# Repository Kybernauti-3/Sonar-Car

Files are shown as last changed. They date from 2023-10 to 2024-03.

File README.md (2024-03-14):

# Sonar-Car
Auticko ktere jezdi po mistnoti a vytváří její mapu

# Použité součástky

2x Rpi pi pico

https://botland.cz/img/art/inne/21574_3.jpg

[Motory kol](https://www.laskakit.cz/dc-motorek-130-3v-16500-rpm/)

[Otočná kontaktní průchodka, 4 vodiče](https://www.laskakit.cz/otocna-kontaktni-pruchodka--4-vodice/)

[Ultrazvukový senzor vzálenosti](https://www.laskakit.cz/ultrazvukovy-meric-vzdalenosti-hc-sr04/)

https://www.laskakit.cz/h-mustek-radic-l9110s/

https://www.laskakit.cz/krokovy-motor-28byj-48/

Mecanum Omni Wheels

Drátování

# Software tohoto projektu je rozdělen na 3 části:

## 1. Program pro řízení vozítka:
Tento program bude řídit pohyb vozítka v souřadnicovém poli. Bude přijímat příkazy k pohybu a posunutí o určitý počet souřadnic (např. 10 cm) v daném směru. Zahrnuje:

- Řízení motorů omniwheelů pro pohyb ve všech směrech.
- Komunikaci přes sériovou linku s druhou deskou.
- API pro přijímání povelů k pohybu o určitý počet souřadnic v daném směru (dopředu, dozadu, doleva, doprava).
- Překlad příkazů na konkrétní pohyby omni kol pro dosažení požadovaného cíle v souřadnicovém poli.

## 2. Program pro mapování místnosti:
Tento program bude kromě mapování také přijímat aktuální polohu vozítka od skriptu pro řízení vozidla. Zahrnuje:

- Vytváření mapy místnosti, kde jedna jednotka bude reprezentovat 10 cm v reálném světě.
- Aktualizaci mapy na základě nových dat z ultrazvukového senzoru.
- Ukládání dat do pole, které reprezentuje mapu místnosti.
- Poskytování těchto informací skriptu pro řízení vozidla.

## 3. Skript pro řízení vozidla na základě mapy:
Tento skript bude řídit pohyb vozidla na základě aktuální mapy místnosti a bude poskytovat aktuální informace o svém pohybu programu pro mapování. Zahrnuje:

- Analýzu dat z mapy a aktuální polohy k rozhodování, kam se vozidlo má pohybovat.
- Generování možných směrů pro pohyb vozidla.
- Vybrat z těchto směrů takový, aby se vozidlo pohnulo pryč a zároveň zabezpečit, aby se v dalším kroku nevrátilo zpět
- Odesílání vybraného směru programu pro řízení vozidla.
- Tímto způsobem bude projekt umožňovat vozítku pohybovat se v místnosti, mapovat prostor a řídit svůj pohyb na základě aktuální mapy.

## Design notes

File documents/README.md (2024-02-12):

# Sonar-Car
Zde se nachází veškeré dokumenty, soupisky a prezentace

# LaTeX

https://www.overleaf.com/read/rbjfbvbgkymk#7530cc

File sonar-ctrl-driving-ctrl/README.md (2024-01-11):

# Sonar-Car
Zde se nachází skripty pro řízení "sonaru" a skript který rozhoduje kam vozidlo pojede

- Měřič na vzdálenost musí být zapojenej ve VBUSu 
- motor taky

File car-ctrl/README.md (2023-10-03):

# Sonar-Car
Zde se nachází skripty pro ovládaní kol auta a jeho pohyb

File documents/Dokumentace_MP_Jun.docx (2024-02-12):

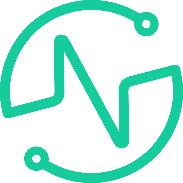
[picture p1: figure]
Obsah obrázku Grafika, Písmo, kruh, symbol Popis byl vytvořen automaticky

Vyšší odborná škola

a Střední průmyslová škola elektrotechnická

Plzeň, Koterovská 85

Dlouhodobá maturitní práce s obhajobou

Téma: Sonar Car

Autor práce: Matěj Jun

Třída: 4. L

Vedoucí práce: Jiří Švihla

Dne: 27. 3. 2024

Hodnocení:

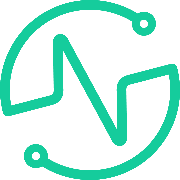
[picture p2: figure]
Obsah obrázku Grafika, Písmo, kruh, symbol Popis byl vytvořen automaticky

Vyšší odborná škola

a Střední průmyslová škola elektrotechnická

Plzeň, Koterovská 85

Zadání dlouhodobé maturitní práce

Žák: Matěj JUN

Třída: 4. L

Studijní obor: 78-42-M/01 Technické lyceum

Zaměření: Kybernetika

Školní rok: 2023 - 2024

Téma práce: Sonar Car

Pokyny k obsahu a rozsahu práce:

1. Seznámení s vývojovou platformou Raspberry Pi Pico
2. Seznámení s modelovacím softwarem
3. Seznámení s problematikou orientace v prostoru a mapováním
4. Tvorba podvozku a návrh řídící elektroniky
5. Návrh a testování mapovací jednotky
6. Tvorba mapovacího skriptu
7. Realizace komunikace mezi jednotkami

Plán konzultací:

19. 10. 2023 Návrh modelu a elektroniky

23. 11. 2023 Kompletace hardwaru

11. 1. 2024 Práce na softwarovém vybavení

8. 2. 2024 Testování mapování a tvorba dokumentace

Určení částí tématu zpracovávaných jednotlivými žáky:

1. Seznámení s vývojovou platformou Raspberry pi pico
2. Seznámení s problematikou orientace v prostoru a mapováním
3. Naprogramujte mapování místnosti
4. Návrh a testování mapovací jednotky
5. Tvorba mapovacího skriptu
6. Realizace komunikace mezi jednotkami

Požadavek na počet vyhotovení maturitní práce: 2 výtisky

Termín odevzdání: 27. března 2024

Čas obhajoby: 15 minut

Vedoucí práce: Jiří ŠVIHLA

Projednáno v katedře ODP a schváleno ředitelem školy.

V Plzni dne: 30. září 2023 Mgr. Vlastimil Volák ředitel školy

## Anotace

Cílem této maturitní práce je vytvoření autonomního vozítka schopného pohybu a mapování místnosti. Práce využívá platformu Raspberry Pi Pico a orientaci vozítka zabezpečuje vzdálenostní senzor umístěný na střeše vozu. Pro pohyb jsou implementována všesměrová kola Mecanum Wheels, která umožňují vozítku pohybovat se ve všech směrech.

„Prohlašuji, že jsem tuto práci vypracoval samostatně a použil(a) literárních pramenů a informací, které cituji a uvádím v seznamu použité literatury a zdrojů informací.“

V Plzni dne: ........................... Podpis: ..............................

## Úvod

V dnešní době, kdy technologický pokrok zaujímá stále větší roli v našich životech, nabývá autonomní robotika a mapování prostoru stále většího významu. Tato maturitní práce si klade za cíl vytvořit malé autonomní vozítko, které se nejenom pohybuje po místnosti, ale také aktivně mapuje své okolí.

Využití platformy Raspberry Pi Pico poskytuje robustní základ pro implementaci řídícího systému vozítka. Hlavním prvkem orientace vozidla je ultrazvukový senzor, který je umístěný na střeše a umožní vozítku získávat informace o okolním prostoru. Pro zajištění plynulého pohybu byla zvolena technologie Omni-wheels, umožňující vozítku pohybovat se ve všech směrech s výjimečnou obratností.

Tato práce nikoli pouze zkoumá technické aspekty vývoje autonomního vozidla, ale také přispívá k pochopení principů autonomní robotiky a mapování prostoru. Výsledky projektu mohou sloužit nejen jako ukázka praktického využití technologií, ale také jako inspirace pro další výzkum v oblasti autonomních systémů.

## 1. Cíle a požadavky

### 1.1. Program pro mapování místnosti

Tento program kromě mapování také přijímá aktuální polohu vozítka od skriptu pro jeho řízení. Zahrnuje:

- Vytváření mapy místnosti, kde jedna jednotka bude reprezentovat 10 cm v reálném světě.
- Přijímání aktuální polohy vozítka od skriptu pro řízení vozidla.
- Aktualizaci mapy na základě nových dat z ultrazvukového senzoru.
- Ukládání dat do pole nebo souboru, který reprezentuje mapu místnosti.
- Poskytování těchto informací skriptu pro řízení vozidla na vyžádání.

### 1.2. Skript pro řízení vozidla na základě mapy

Skript bude řídit pohyb vozidla na základě aktuální mapy místnosti a poskytuje aktuální informace o svém pohybu části programu pro mapování. Zahrnuje:

- Pravidelně aktualizovat program pro mapování o svůj aktuální pohyb, včetně souřadnic.
- Analýzu dat z mapy a aktuální polohy k rozhodování, kam se vozidlo má pohybovat.
- Generování příkazů pro pohyb vozidla o určitý počet souřadnic (např. 10 cm) od překážky.
- Odesílání těchto příkazů programu pro řízení vozítka.
- Tímto způsobem bude projekt umožňovat vozítku pohybovat se v místnosti, mapovat prostor a řídit svůj pohyb na základě aktuální mapy.

## 2. Použité součástky

### 2.1. Raspberry Pi Pico W

Raspberry Pi Pico W je vývojová deska s mikrokontrolérem, která je založena na čipu RP2040 od společnosti Raspberry Pi Foundation. Čip obsahuje dvoujádrový procesor ARM Cortex-M0+ s taktem až 133 MHz, 264 kB paměti RAM a 2 MB vestavěné paměti Flash. Deska má 28 GPIO pinů, které lze použít pro připojení různých periferních zařízení, jako jsou senzory, LED diody, motory atd.

Vývojová deska Raspberry Pi Pico W je vhodná pro širokou škálu aplikací, včetně IoT, automatizace, domácí elektroniky a dalších. Je cenově dostupná a snadno se používá, což z ní činí ideální volbu pro začátečníky i pokročilé uživatele.

V tomto projektu je díky této desce ovládán krokový motor, zpracovávány data z ultrazvukového senzoru a řízeno celé vozítko. Verze s Wifi byla také zvolena pro možnost později mapu přenášet bezdrátově.

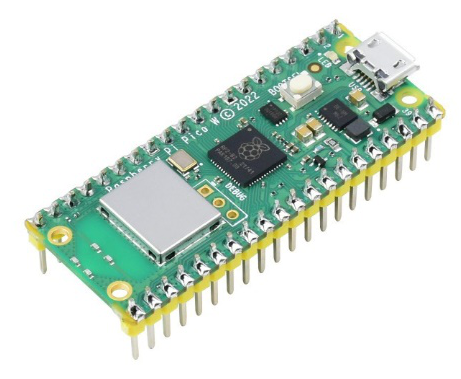
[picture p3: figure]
Raspberry Pi Pico W with Soldered Headers - RP2040 - WS-23289

Obrázek 1 - Raspberry Pi Pico W [Zdroj: https://www.tinytronics.nl/shop/image/cache/catalog/products_2023/raspberry-pi-pico-w-with-soldered-headers-rp2040-800x800.jpg]

### 2.2. Ultrazvukový senzor vzdálenosti

Ultrazvukový měřič vzdálenosti HC-SR04 je kompaktní a cenově dostupný senzor, který měří vzdálenost od překážky pomocí ultrazvukových vln. Senzor má pracovní rozsah od 2 cm do 4 m a přesnost měření až 3 mm.

Senzor pracuje na principu odrazu ultrazvukových vln od překážky. Senzor vysílá krátký impuls ultrazvukových vln a poté čeká na jejich odražení od překážky. Doba, za kterou se ultrazvukové vlny odrazí, se používá k výpočtu vzdálenosti od překážky.

V tomto projektu je použit pro měření vzdálenosti mezi „sonarem“ na vozítku a překážkami či zdmi.

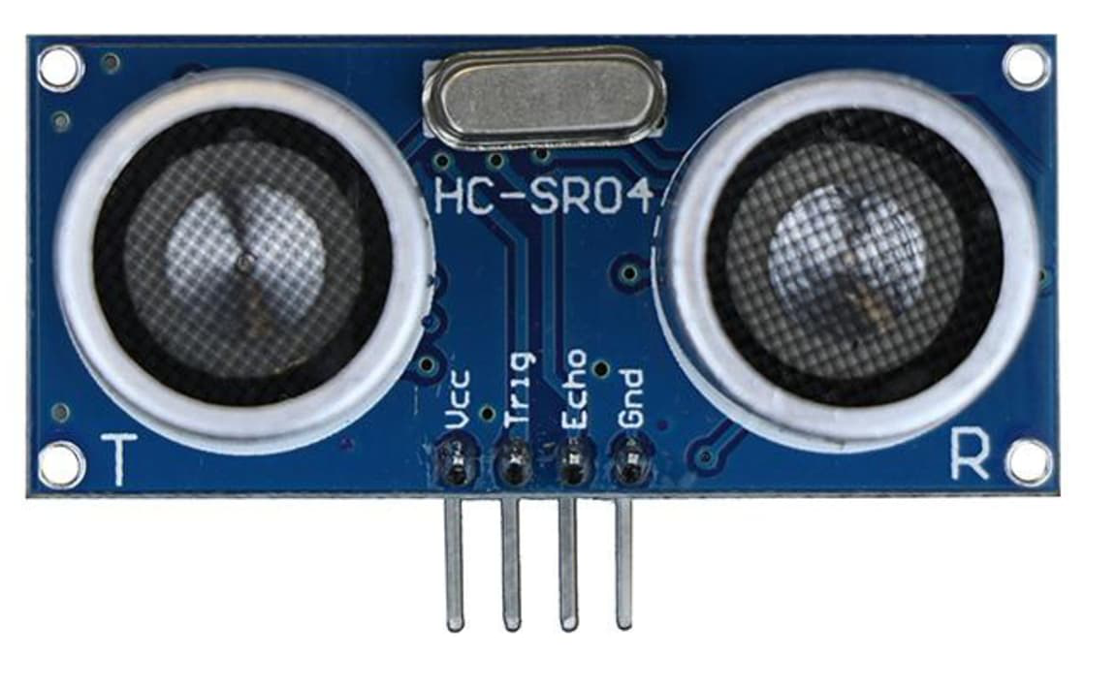
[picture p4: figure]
46130 | Ultrasonic Distance Sensor HC-SR04 5V Ve | RS

Obrázek 2 - Ultrazvukový měřič vzdálenosti HC-SR04 [Zdroj: https://cz.rs-online.com/web/p/doplnky-bbc-micro-bit/2153181] (https://cz.rs-online.com/web/p/doplnky-bbc-micro-bit/2153181)

### 2.3. Krokový motor

Krokový motor 28BYJ-48 je malý a cenově dostupný krokový motor, který se často používá v robotických aplikacích. Motor má 4 fáze a 48 zubů, což znamená, že pro jednu otáčku motoru je potřeba 48 kroků.

Motor pracuje na principu krokování, při kterém se motor otáčí po malém úhlu v každém kroku. Tímto způsobem lze motor ovládat přesně a plynule.

V tomto projektu je použit pro otáčení „sonaru“ s ultrazvukovým senzorem vzdálenosti.

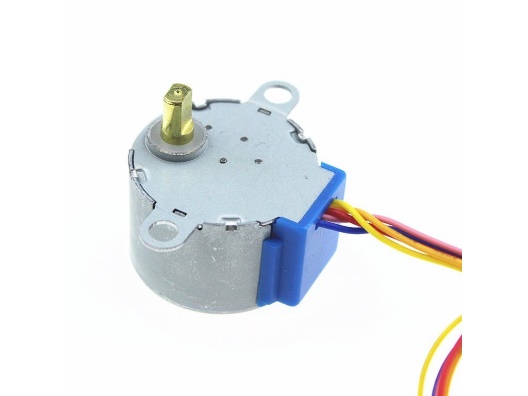
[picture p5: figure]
Obsah obrázku kabel, Elektrické vedení Popis byl vytvořen automaticky

Obrázek 3 - Krokový motor 28BYJ-48 [Zdroj: https://www.laskakit.cz/krokovy-motor-28byj-48/]

### 2.4. Řadič ULN2003

Díky řadiči ULN2003 lze s krokovým motorem jednoduše otáčet.

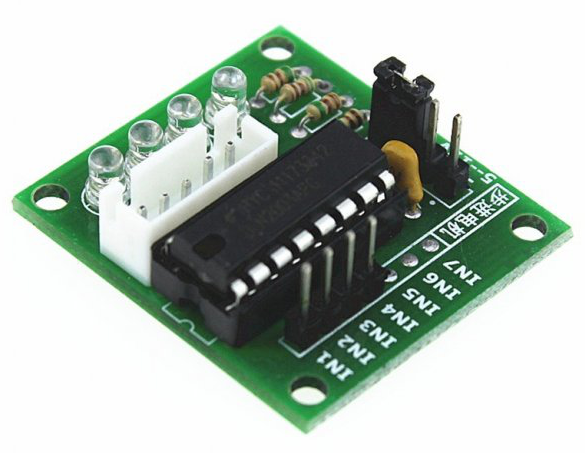
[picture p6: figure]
Obsah obrázku elektronika, Elektronická součástka, Obvodoví součástka, Pasivní součástka Popis byl vytvořen automaticky

Obrázek 4 - Řadič ULN2003 [Zdroj: https://www.laskakit.cz/radic-uln2003-pro-krokovy-motor/]

### 2.5. RGB LED

RGB LED je zkratka pro Light Emitting Diode (LED) s třemi základními barvami – červenou, zelenou a modrou. Jedná se o speciální typ LED diody, který umožňuje nezávislé ovládání těchto tří barev, což umožňuje vytváření široké škály barevných kombinací.

Zde je použita pro signalizování stavu sonaru.

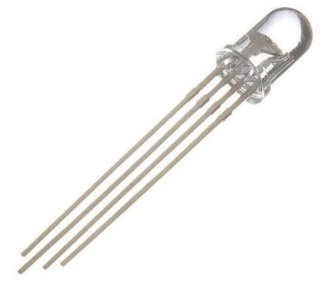
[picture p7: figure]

Obrázek 5 - RGB LED [Zdroj: https://dratek.cz/docs/produkty/1/1298/1434544602.pdf]

## 3. Ovládání sonaru

### 3.1. Měření vzdálenosti

„Sonar“ měří vzdálenost k objektu pomocí ultrazvukového senzoru (viz v kapitole použitých součástek). Senzor nejprve vysílá ultrazvukový impuls, který se odrazí od objektu a vrátí se zpět k senzoru. Čas, který impuls stráví cestou tam a zpět, se pak použije k výpočtu vzdálenosti k objektu pomocí vzorce:

vzdálenost= (čas*rychlost zvuku)/2

Jelikož impuls letí k překážce, kde se odrazí a stejnou rychlostí letí zpět je nutné vzdálenost vydělit dvěma. Funkce, která zajišťuje správný výpočet, vrací právě tuto přepočítanou vzdálenost, která je dále používána při zpracování mapy.

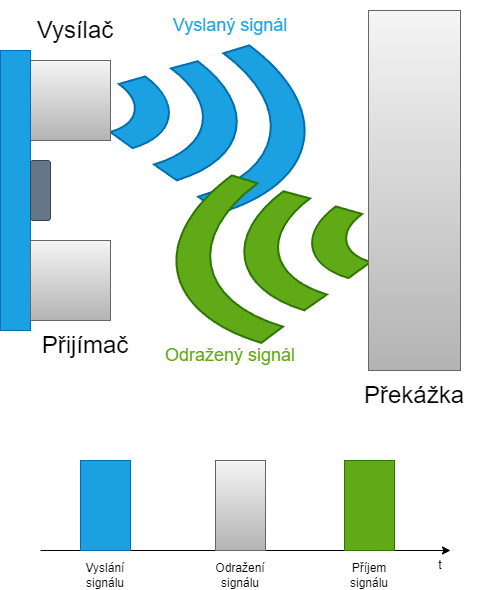
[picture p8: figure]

Obrázek 6 – Měření vzdálenosti [Zdroj: vlastní, vytvořeno pomocí draw.io]

### 3.2. Otáčení sonaru

Otáčení sonaru je zajištěno pomocí krokového motoru, který pohání mechanismus otáčení. Motor je ovládán příslušným řadičem, který přijímá signály z Raspberry Pi Pica a generuje odpovídající krokové impulzy. Tyto impulzy pohybují motorem a tím otáčejí sonar do požadovaného směru. Pro dosažení přesného a plynulého otáčení je nutné řádně řídit frekvenci a počet kroků motoru.

### 3.3. Taktika mapování

Taktika mapování místnosti je založena na pravidelném pohybu vozítka po místnosti s pevně definovanou taktikou. Vozítko je řízeno tak, aby se pohybovalo vždy o určitý krok, například 10 cm, od stěn místnosti, což odpovídá jedné souřadnici v mapě. Tímto způsobem je postupně zmapován celý prostor místnosti, zatímco senzor neustále snímá vzdálenost od překážek.

### 3.4. Vytváření mapy

Vytváření mapy místnosti je proces, při kterém jsou sbírána data z ultrazvukového senzoru a ukládána do pole reprezentujícího mapu. Každé snímání vzdálenosti od překážek je interpretováno jako bod v mapě, kde jednotlivé body jsou rozloženy v souřadnicovém systému. Na základě těchto bodů je poté vytvořena mapa místnosti, která poskytuje informace o umístění překážek a volných prostorů v místnosti. Tato mapa může být dále využita k navigaci vozítka v prostoru.

## 4. Model sonaru

### 4.1. Modelovací prostředí

Pro vymodelování sonaru byl zvolen program Autodesk Inventor Professional 2023. Je to profesionální program pro modelování komplexnějších modelů. Používá se hlavně v průmyslu k modelování například aut, bagrů či jiných průmyslových strojů.

V tomto projektu je použit pro vytvoření detailního modelu krabičky pro sonar.

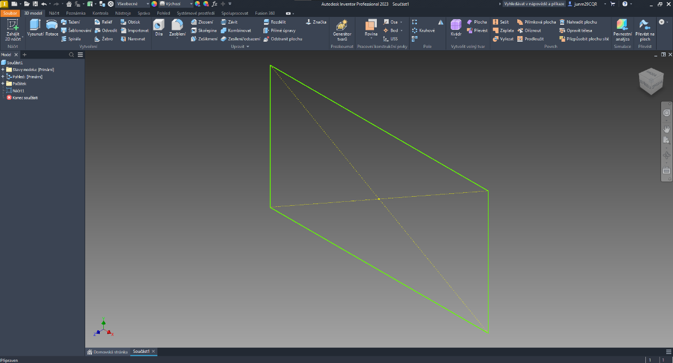
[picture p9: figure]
Obsah obrázku text, snímek obrazovky, software, Multimediální software Popis byl vytvořen automaticky

Obrázek 7 - Modelovací prostředí programu Autodesk Inventor [Zdroj: vlastní]

### 4.2. Postup modelování

Nejprve bylo důležité zvolit správné rozložení komponent v krabičce a zvolit jednoduchý, ale moderní a „vzdušný“ design.

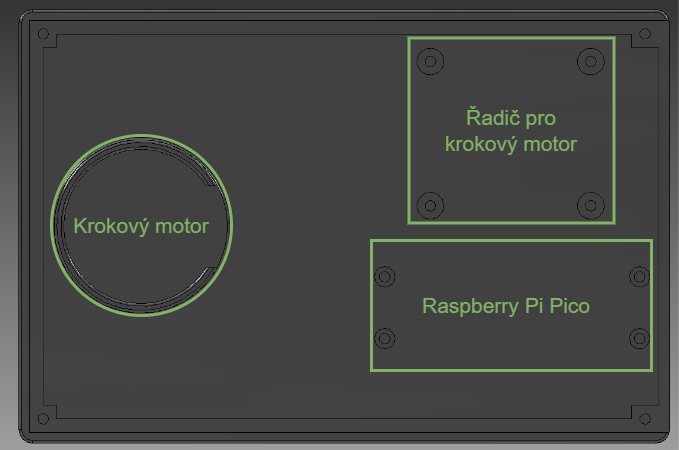
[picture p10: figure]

Obrázek 8 - Rozložení komponent v krabičce [Zdroj: vlastní, vytvořeno pomocí draw.io]

## 5. Závěr

Pokročilá verze tohoto sonaru, známá jako LiDAR (Light Detection And Ranging), otevírá široké možnosti využití. LiDAR lze použít nejen k mapování místností, ale také k měření vzdálenosti, mapování terénu, monitorování atmosférických jevů a mnoha dalším aplikacím. Výsledky tohoto projektu poskytují solidní základ pro další vývoj a vylepšení, což může vést k vytvoření pokročilejších a přesnějších systémů mapování. Tento projekt ukazuje, jak jednoduché vozítko s jednoduchými součástkami a programováním může mít široké uplatnění a přinášet užitek v mnoha odvětvích.

Díky své flexibilitě a snadnému použití může tento projekt sloužit jako inspirace pro budoucí inovace v oblasti autonomních robotických systémů. Rozvoj a zdokonalení tohoto konceptu mohou přinést revoluci v průmyslu, výzkumu a každodenním životě.

Nicméně, i přes své úspěchy a potenciál, je třeba si uvědomit některé výzvy, jako je například zvýšení přesnosti mapování, optimalizace algoritmů pro navigaci a zvýšení odolnosti vozítka v různých prostředích. Tyto výzvy představují zajímavé výzkumné a vývojové možnosti pro budoucí práce v oblasti autonomní robotiky.

V závěru lze konstatovat, že projekt Sonar Car může představovat pouze začátek dlouhé cesty směrem k vytvoření efektivních a inteligentních autonomních systémů, které mohou přinést reálný přínos jak pro průmysl, tak pro společnost jako celek.

## 6. Seznam obrázků

## 7. Seznam příloh

Příloha I: Výkres boxu

Příloha II: Výkres vrchní strany boxu

Příloha III: Výkres sonaru

Příloha IV: Výkres pomocného kroužku

Příloha V: Veškeré kódy a software (elektronicky)

## 8. Zdroje

https://www.raspberrypi.com/documentation/

https://www.laskakit.cz/raspberry-pi-pico/

https://www.raspberrypi.com/products/raspberry-pi-pico/

https://www.laskakit.cz/arduino-ultrazvukovy-meric-vzdalenosti-hc-sr04/

https://dratek.cz/docs/produkty/1/1298/1434544602.pdf

https://www.laskakit.cz/radic-uln2003-pro-krokovy-motor/

https://lastminuteengineers.com/arduino-sr04-ultrasonic-sensor-tutorial/

https://cs.wikipedia.org/wiki/Lidar

Raspberry Pi Documentation. [Online] [Citováno dne: 18.1. 2024].

Dostupné z: https://www.raspberrypi.com/documentation/

LaskaKit. Raspberry Pi Pico. [Online] [Citováno dne: 18.1. 2024].

Dostupné z: https://www.laskakit.cz/raspberry-pi-pico/

Raspberry Pi. Raspberry Pi Pico. [Online] [Citováno dne: 18.1. 2024].

Dostupné z: https://www.raspberrypi.com/products/raspberry-pi-pico/

LaskaKit. Arduino ultrazvukový měřič vzdálenosti HC-SR04. [Online] [Citováno dne: 18.1. 2024].

Dostupné z: https://www.laskakit.cz/arduino-ultrazvukovy-meric-vzdalenosti-hc-sr04/

Dratek. [PDF] ULN2003. [Citováno dne: 18.1. 2024].

Dostupné z: https://dratek.cz/docs/produkty/1/1298/1434544602.pdf

LaskaKit. Řadič ULN2003 pro krokový motor. [Online] [Citováno dne: 18.1. 2024].

Dostupné z: https://www.laskakit.cz/radic-uln2003-pro-krokovy-motor/#relatedFiles

Last Minute Engineers. Arduino HC-SR04 Ultrasonic Sensor Tutorial. [Online] [Citováno dne: 18.1. 2024].

Dostupné z: https://lastminuteengineers.com/arduino-sr04-ultrasonic-sensor-tutorial/

OpenAI. Chat. [Online]. [Citováno dne: 11.1. 2024].

Dostupné z: https://chat.openai.com/

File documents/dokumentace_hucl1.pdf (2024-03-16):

### Vyšší odborná škola a Střední průmyslová škola elektrotechnická Plzeň, Koterovská 85

## DLOUHODOBÁ MATURITNÍ PRÁCE S OBHAJOBOU

Téma: | Sonar Car
Autor práce: | Tomáš Hucl
Třída: | 4. L
Vedoucí práce: | Jiří Švihla
Dne: | 27. 3. 2024

Hodnocení:

Vyšší odborná škola
a Střední průmyslová škola elektrotechnická Plzeň, Koterovská 85

## Zadání dlouhodobé maturitní práce

Žák: | Tomáš HUCL
Třída: | 4. L
Studijní obor: | 78-42-M/01 Technické lyceum
Zaměření: | Kybernetika
Školní rok: | 2023 - 2024
Téma práce: | Sonar Car

Pokyny k obsahu a rozsahu práce:

1. Seznámení s vývojovou platformou Raspberry Pi Pico 2. Seznámení s modelovacím softwarem 3. Seznámení s problematikou orientace v prostoru a mapováním 4. Tvorba podvozku a návrh řídící elektroniky 5. Návrh a testování mapovací jednotky 6. Tvorba mapovacího skriptu 7. Realizace komunikace mezi jednotkami

Plán konzultací:
19. 10. 2023 Návrh modelu a elektroniky
23. 11. 2023 Kompletace hardwaru
11. 1. 2024 Práce na softwarovém vybavení
8. 2. 2024 Testování mapování a tvorba dokumentace

Určení částí tématu zpracovávaných jednotlivými žáky:

### 1. Seznámení s vývojovou platformou Raspberry pi pico 2. Seznámení s modelovacím softwarem 3. Tvorba podvozku 4. Návrh řídící elektroniky 5. Realizace komunikace mezi jednotkami

Požadavek na počet vyhotovení maturitní práce: 2 výtisky
Termín odevzdání: | 27. března 2024
Čas obhajoby: | 15 minut
Vedoucí práce: | Jiří ŠVIHLA

Projednáno v katedřeODP a schváleno ředitelem školy.

V Plzni dne: 30. září 2023 | Mgr. Vlastimil
Volák | ředitel školy

## Anotace

Cílem této maturitní práce je vytvoření autonomního vozítka schopného pohybu a mapování místnosti. Práce využívá platformu Raspberry Pi Pico a orientaci vozítka zabezpečuje vzdálenostní senzor umístěný na střeše vozu. Pro pohyb jsou implementována všesměrová kola Mecanum Wheels, která umožňují vozítku pohybovat se ve všech směrech.

„Prohlašuji, že jsem tuto práci vypracoval samostatně a použil(a) literárních pramenů a informací, které cituji a uvádím v seznamu použité literatury a zdrojů informací.“

V Plzni dne: | Podpis: |

4

## Obsah

4. Seznam obrázků | Chyba! Záložka není definována.
5. Seznam příloh | Chyba! Záložka není definována.
6. Zdroje | Chyba! Záložka není definována.

5

## Úvod

V dnešní době, kdy technologický pokrok zaujímá stále větší roli v našich životech, nabývá autonomní robotika a mapování prostoru stále většího významu. Cílem této maturitní práce je vytvořit malé autonomní vozítko, které se nejenom pohybuje po místnosti, ale také aktivně mapuje své okolí.

Využití platformy Raspberry Pi Pico poskytuje robustní základ pro implementaci řídícího systému vozítka. Klíčovým prvkem orientace vozidla je vzdálenostní senzor umístěný na střeše, umožňující vozítku získávat informace o okolním prostoru. Pro pohyb jsou implementována všesměrová kola Mecanum Wheels, umožňující vozítku pohybovat se ve všech směrech se skvělou obratností.

Tato práce se nezaměřuje pouze na technické aspekty vývoje autonomního vozidla, ale také přispívá k pochopení principů autonomní robotiky a mapování prostoru. Výsledky projektu mohou posloužit nejen jako ukázka praktického využití technologií, ale i jako inspirace pro další výzkum v oblasti autonomních systémů.

6

## 1. Cíle a požadavky

### 1. Program pro řízení vozítka:

Tento program bude řídit pohyb vozítka v souřadnicovém poli. Bude přijímat příkazy k pohybu a posunutí o určitý počet souřadnic (např. 10 cm) v daném směru. Zahrnuje:

Řízení motorů s Mecanum Wheels pro pohyb ve všech směrech.
Komunikaci přes sériovou linku s druhou deskou.
API pro přijímání povelů k pohybu o určitý počet souřadnic v daném směru (dopředu, dozadu, doleva, doprava).
Překlad příkazů na konkrétní pohyby omni kol pro dosažení požadovaného cíle v souřadnicovém poli.

### 2. Zapojení:

Zapojení všech elektronických částí tak, aby vše fungovalo dle programu pro řízení celého vozítka.

### 3. Model vozítka:

Náčrt a kompletní vymodelování všech potřebných součástek v programu Autodesk Inventor.

### 4. Kompletace:

Úplné namontování a zapojení všech součástek do vymodelovaného vozítka.

7

## 2. Použité součástky

### 2.1. TT motor s převodovkou

TT motor s převodovkou je motor používaný často v lehčích robotických zařízeních kvůli svým plastovým převodům.
Rozměry: 70x22x18mm
Váha motoru: 50g
Pro napájení DC 5V platí tyto parametry: Výstupní otáčky: 197ot/min
Proud: 100mA

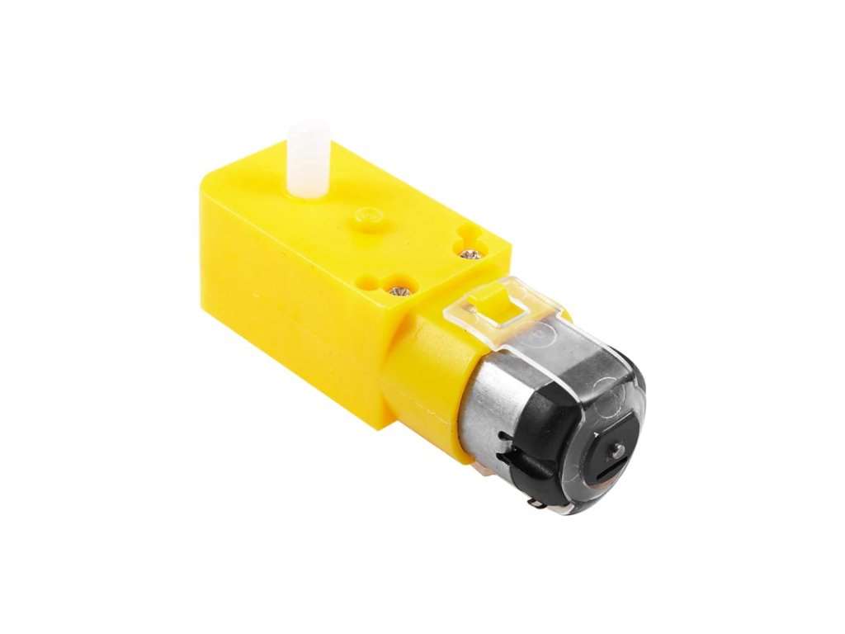
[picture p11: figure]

Obrázek 1– TT motor s převodovkou [Zdroj: https://www.laskakit.cz/tt-motor-s-prevodovkou-plastove-prevody/]

8

### 2.2. Raspberry Pi Pico

Raspberry Pi Pico je vývojová deska od společnosti Raspberry Pi Foundation. Nejdůležitějším prvkem této platformy je mikrokontrolér RP2040, který nabízí dvě jádra ARM Cortex-M0+ a poskytuje dostatečný výkon pro rozmanité vestavěné projekty.
V tomto projektu bude Raspberry Pi Pico ovládat celkový pohyb vozítka.
Rozměry: 21x51x1mm

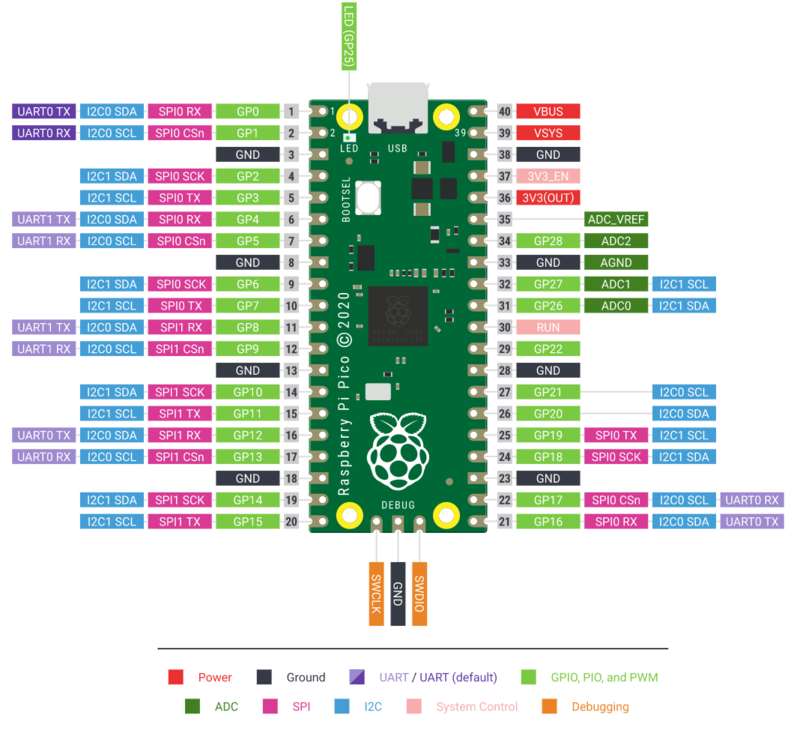
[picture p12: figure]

Obrázek 2– Raspberry Pi Pico [Zdroj: https://learn.adafruit.com/getting-started-with-raspberry-pi-pico-circuitpython/pinouts]

9

### 2.3. H-můstek

H-můstek L9110S je integrovaný obvod, který slouží k ovládání dvou stejnosměrných motorů. Tento modul je často používán v elektronických projektech, kde je potřeba pohybovat se dvěma motory. V našem vozítku budou dva tyto můstky.
Rozměry: 28x21mm
Vstupní napětí: 2.5-12VDC
Trvalý proud: až 800mA na kanál

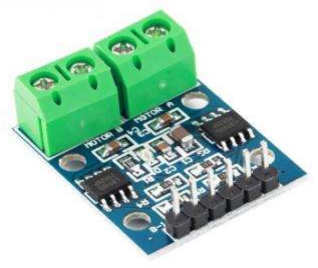
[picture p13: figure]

Obrázek 3- H-můstek L9110S [Zdroj: https://www.gsmcentrum.cz/h-mustek-modul-l9110s]

10

## 3. Zapojení, schéma

### 3.1. Schéma

### 3.2. Zapojení

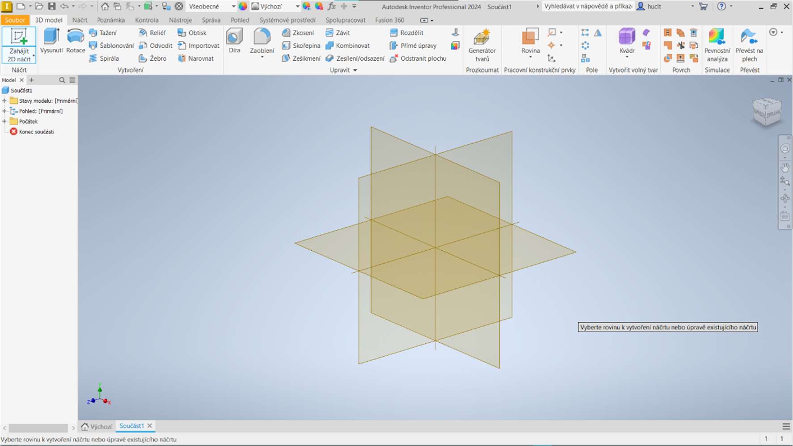
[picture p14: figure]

11

## 4. Model vozidla

### 4.1. Modelovací prostředí

Na vymodelování vozítka jsem si vybral Autodesk Inventor Professional 2024. Inventor je profesionální program a slouží převážně ve strojírenství k navrhování 3D prototypů. Inventor nabízí spoustu nástrojů pro 3D návrhy součástí a sestav, ze kterých jde následně udělat výkres.
Inventor jsem v tomto projektu použil na vymodelování jednotlivých součástí vozidla.

Obrázek 4- Vývojové prostředí Autodesk Inventor [Zdroj: Vlastní]

### 4.2. Modelování

Nejprve bylo nutné určit si potřebné rozměry auta tak, aby vše pasovalo tak, jak má a vešla se do něho všechna elektronika.

12

První část auta (karoserie) – horní část auta kde bude všechna elektronika, kromě motorů.

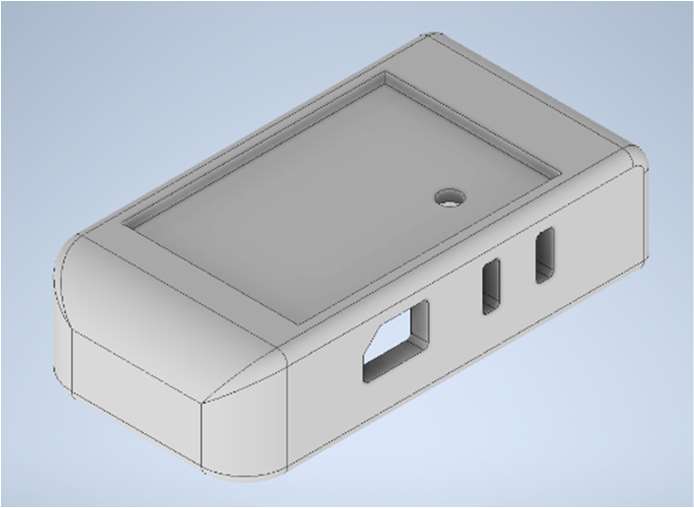
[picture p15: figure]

Obrázek 5- Karoserie [Zdroj: Vlastní]

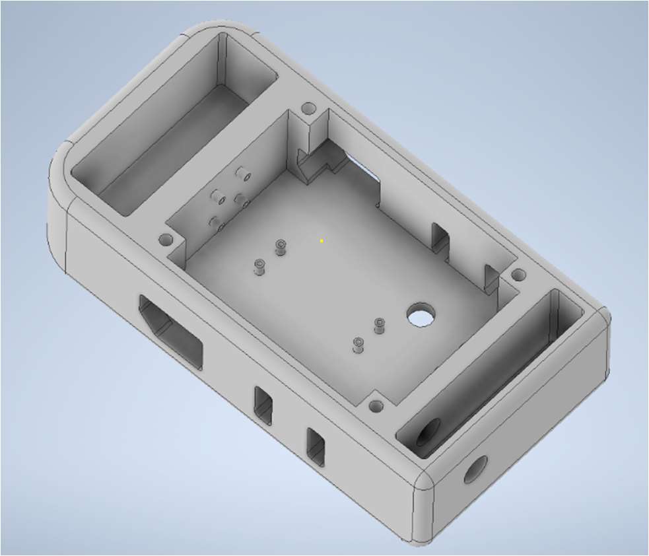
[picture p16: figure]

Obrázek 6- Karoserie [Zdroj: Vlastní]

Druhá část auta (podvozek) – celý podvozek s vysunutím na motory, powerbanku a díry na kabely, které povedou k H-můstkům.

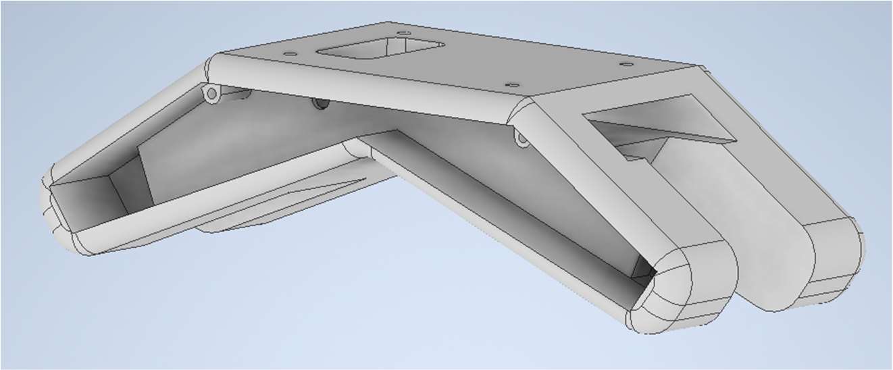
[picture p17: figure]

Obrázek 7- Podvozek [Zdroj: Vlastní]

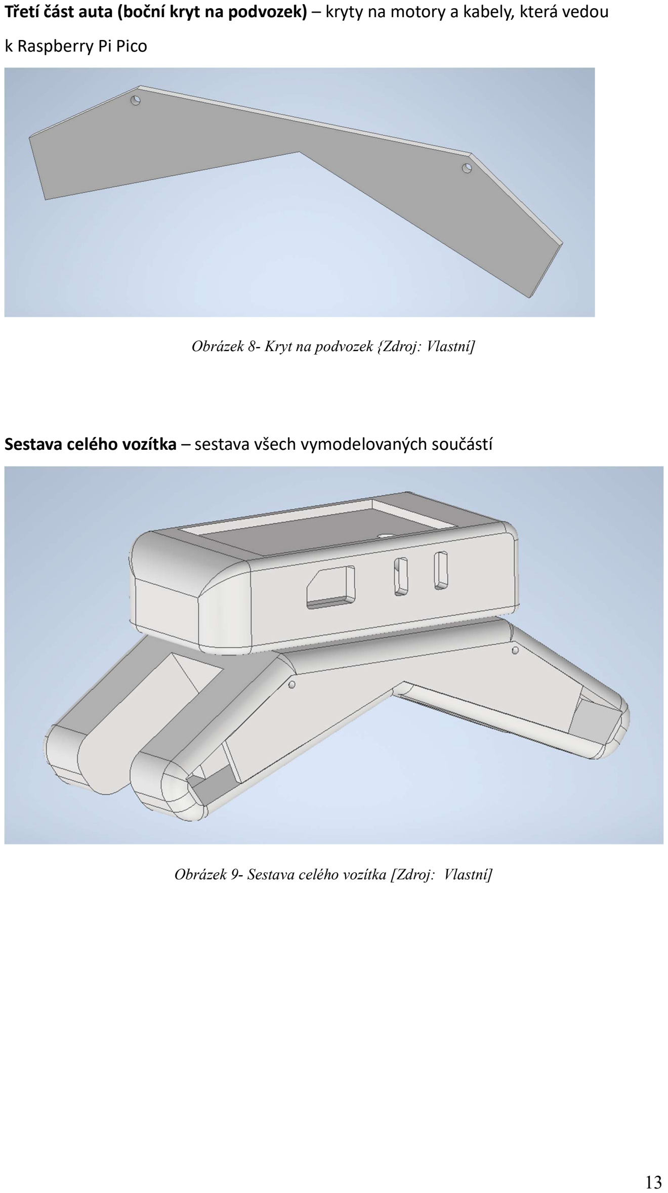
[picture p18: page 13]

13

Třetí část auta (boční kryt na podvozek) – kryty na motory a kabely, která vedou k Raspberry Pi Pico

Obrázek 8- Kryt na podvozek {Zdroj: Vlastní]

Sestava celého vozítka – sestava všech vymodelovaných součástí

Obrázek 9- Sestava celého vozítka [Zdroj: Vlastní]

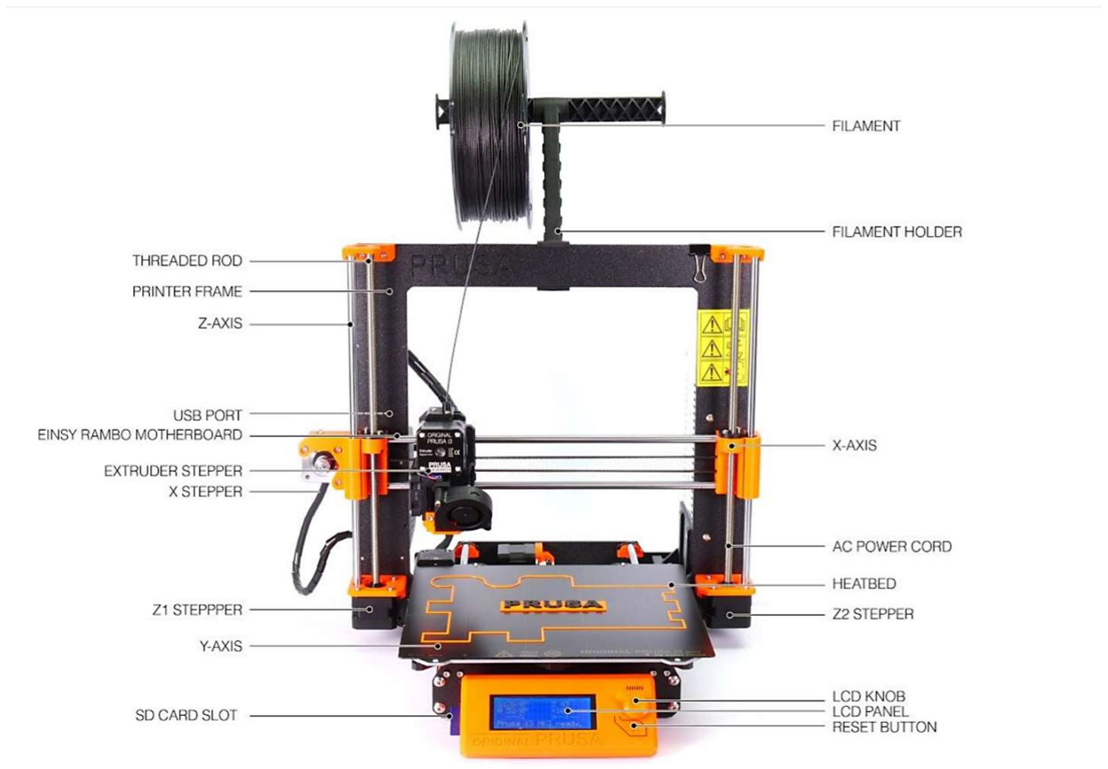
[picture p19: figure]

14

## 5. 3D Tisk

Může se nazývat i Aditivní výroba a je to technologie, která nám umožňuje vytvořit fyzický objekt na základě modelu, který je vytvořen v nějakém 3D prostředí (Autodesk Inventor). 3D model se nejdříve musí převést do formátu, ze kterého se může být použit pro 3D tisk. Model se tiskne vrstva po vrstvě. Nejpoužívanější materiály jsou plast, beton, keramika, kov.
Využití má například ve zdravotnictví, automobilový průmysl, architektura. Umožňuje výrobu složitých tvarů, které by bylo jinak těžké vyrobit.
Na tisk jsem použil tiskárnu original prusa i3 mk3.

Obrázek 10- Origina Prusa i3 mk3 [Zdroj: https://help.prusa3d.com/cs/article/pravidelna-udrzba-tiskarny-i3_2072]

15

### 5.1. Program na 3D tisk

Na tisk jsem použil program PrusaSlicer. Program jsem použil, protože v něm umím pracovat, je to jednoduché a tiskl jsem na tiskárnách od této firmy.
Bylo nutné nastavit parametry k tisku a rozložení modelů na desce. Když bylo vše připravené, mohl jsem nahrát soubor na flash disk, který jsem následně dal do tiskárny.

Obrázek 1,2,3 (dodělat!)

### 5.2. Hotový model vozítka

Všechny součásti se tiskly celkem 41 hodin a byly použity různé typy filamentu.

Obrázek 1,2,3 (dodělat!)

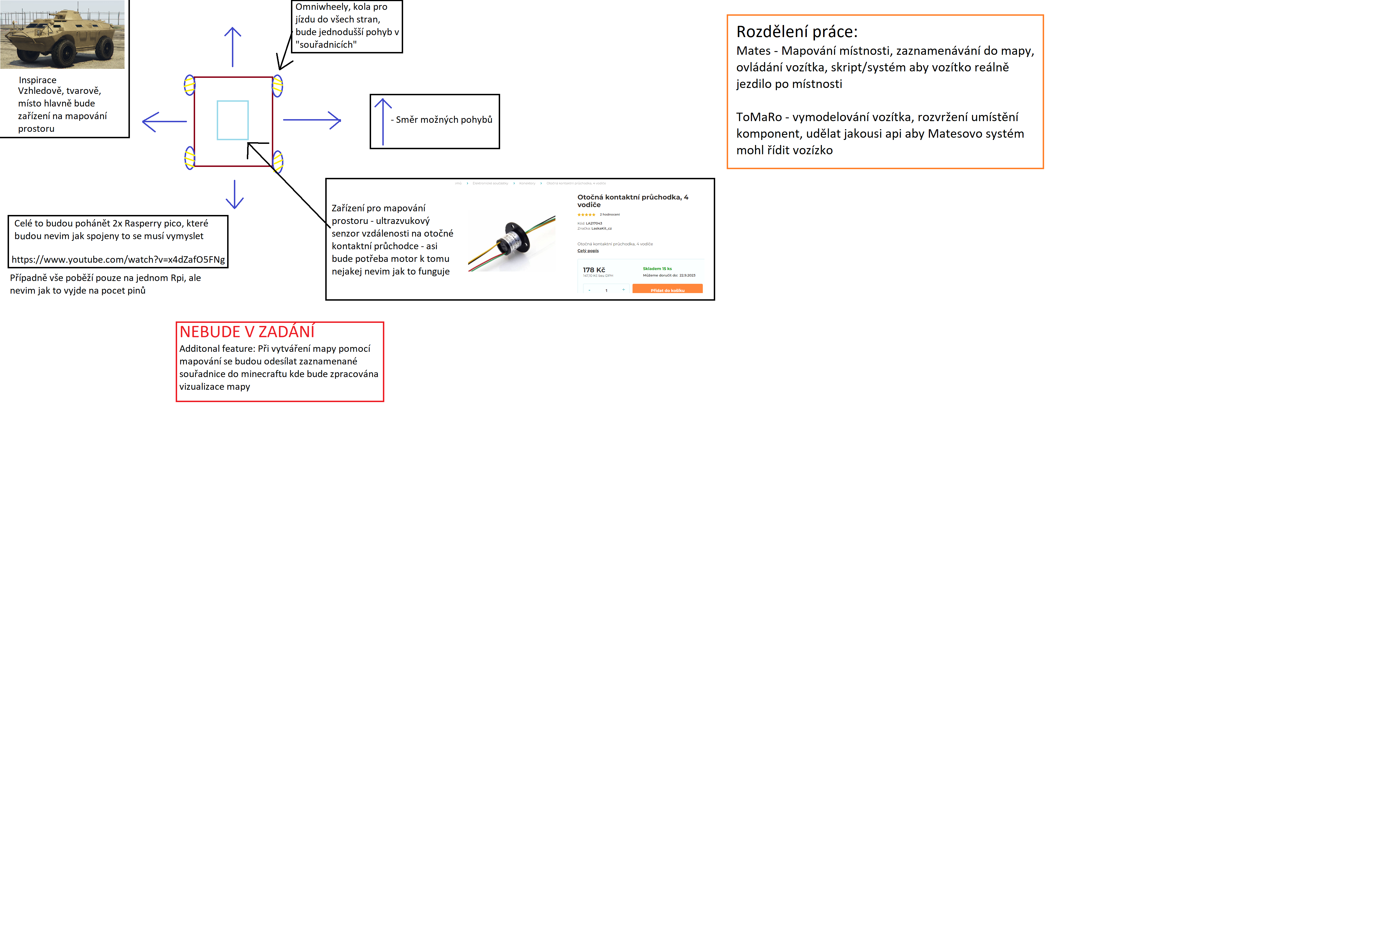
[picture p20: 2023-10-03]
documents/first look.png

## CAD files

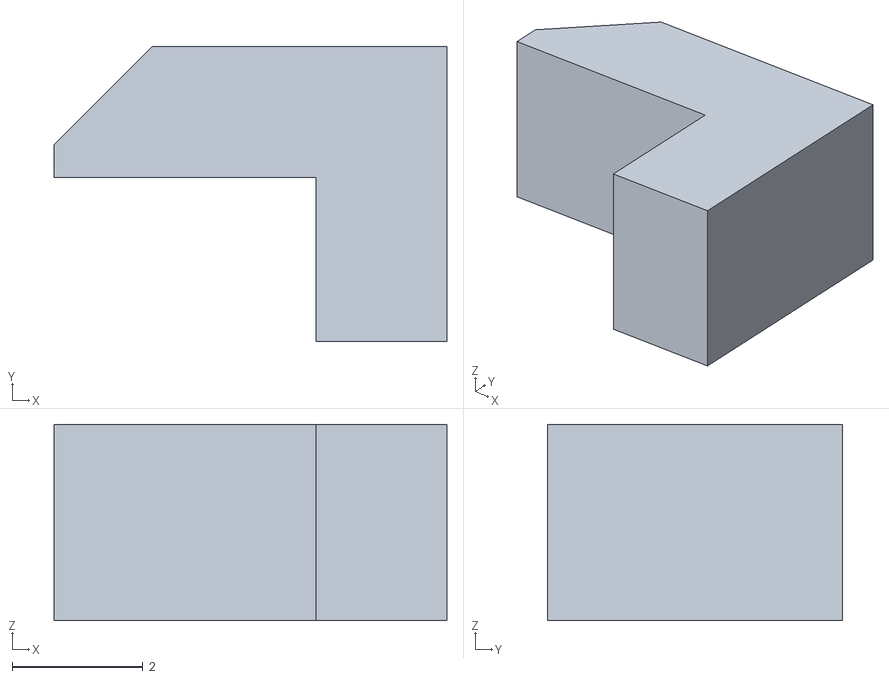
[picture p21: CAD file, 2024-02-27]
models/Sonar/sonar-liner.stl
6.00 x 4.50 x 3.00

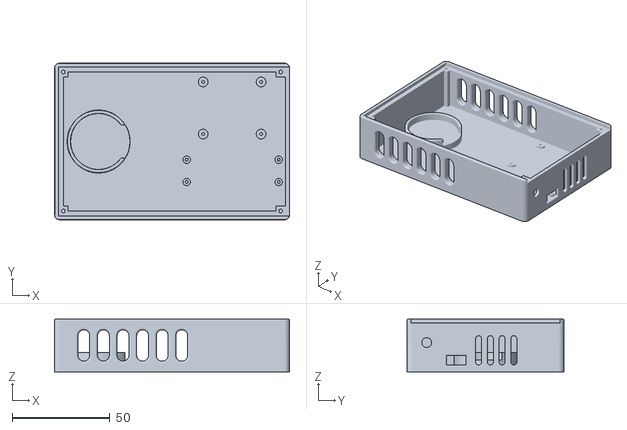
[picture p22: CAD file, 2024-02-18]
models/Sonar/box.stl
120.0 x 80.0 x 27.0

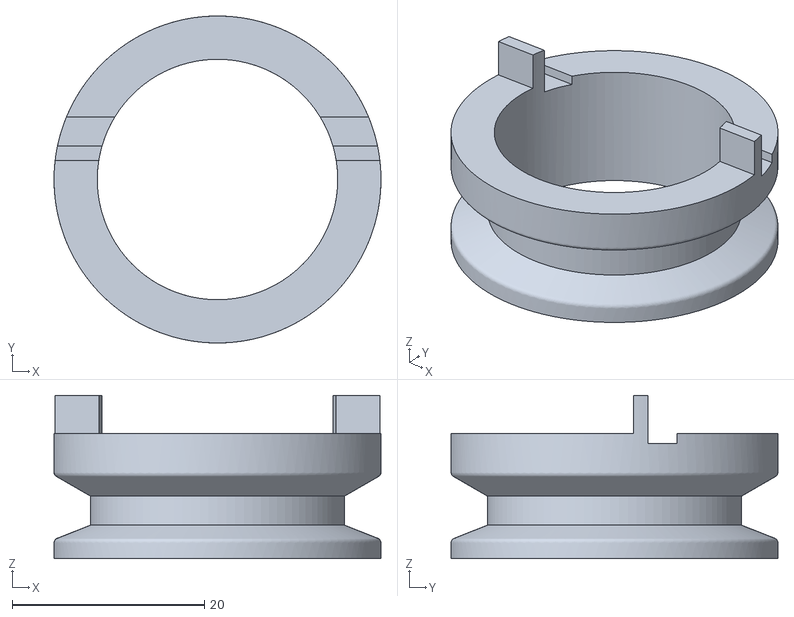
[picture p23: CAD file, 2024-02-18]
models/Sonar/sonar.stl
34.0 x 34.0 x 17.0

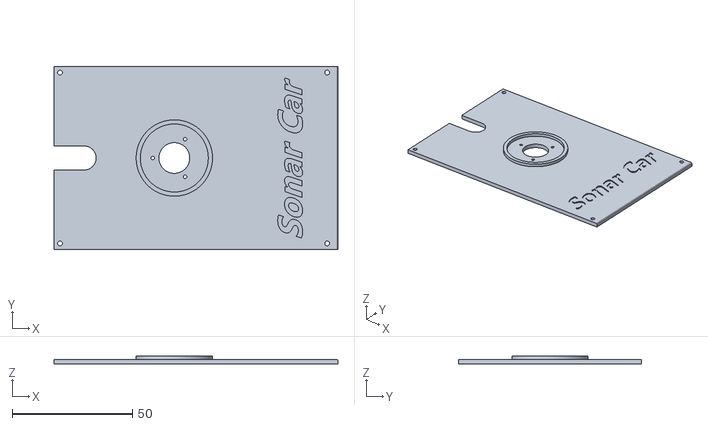
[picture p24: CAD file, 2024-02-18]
models/Sonar/box-top.stl
118.0 x 76.0 x 3.50

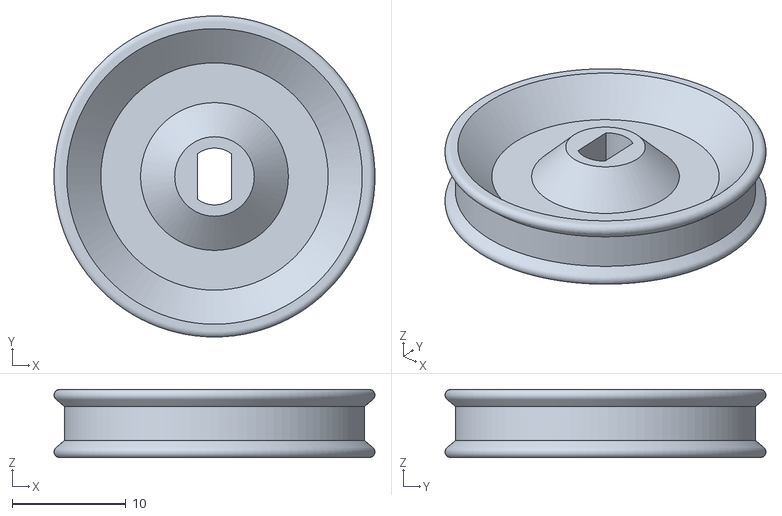
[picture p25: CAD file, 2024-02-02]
models/Sonar/rub-ring.stl
28.2 x 28.2 x 6.00

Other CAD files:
models/Sonar/vykresy/Příloha I box.dwg
models/Sonar/vykresy/Příloha II Víko boxu.dwg
models/Sonar/vykresy/Příloha IV Kroužek.dwg
models/Sonar/vykresy/Příloha VI Sonar - sestavený.dwg
models/Sonar/vykresy/Příloha III Držák senzoru.dwg
models/Sonar/vykresy/Příloha V Vodící zobáček.dwg
models/Sonar/OldVersions/Vodící zobáček.0003.dwg
models/Sonar/vykresy/OldVersions/Příloha IV Kroužek.0001.dwg
models/Sonar/vykresy/OldVersions/Příloha II Víko boxu.0002.dwg
models/Sonar/vykresy/OldVersions/Příloha II Výkres víka boxu.0001.dwg
models/Sonar/vykresy/OldVersions/Příloha I Box.0001.dwg
models/Sonar/OldVersions/Sonar-Box.0041.iam
models/Sonar/OldVersions/box.0046.ipt
models/Sonar/OldVersions/rub-ring.0014.ipt
models/Sonar/OldVersions/sonar-liner.0005.ipt
models/Sonar/OtocnaKontaktniPruchodka.ipt
models/Sonar/Sonar-Box.iam
models/Sonar/StepperMotor.ipt
models/Sonar/UltraZvuk.ipt
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

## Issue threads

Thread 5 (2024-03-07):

Check new tuning in sonar_control

mates-exe, 2024-03-07:
- [x] MQTT sending map
- [x] Algorithm to decide where2go should be working
- [x] Done some preps for UART communication with chassis

Get ready to map & drive!

Closed 2024-03-14.

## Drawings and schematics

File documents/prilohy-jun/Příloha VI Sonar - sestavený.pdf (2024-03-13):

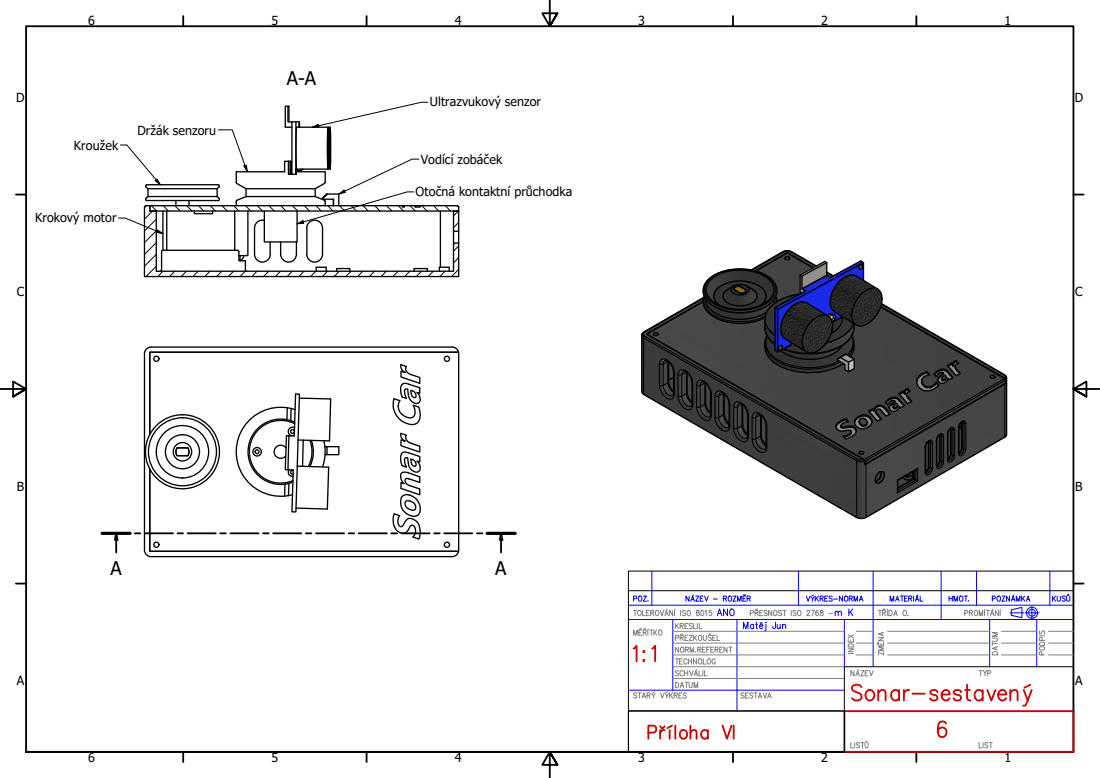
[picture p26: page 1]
Ultrazvukový senzor; Držák senzoru; Vodící zobáček; Krokový motor

Otočná kontaktní průchodka

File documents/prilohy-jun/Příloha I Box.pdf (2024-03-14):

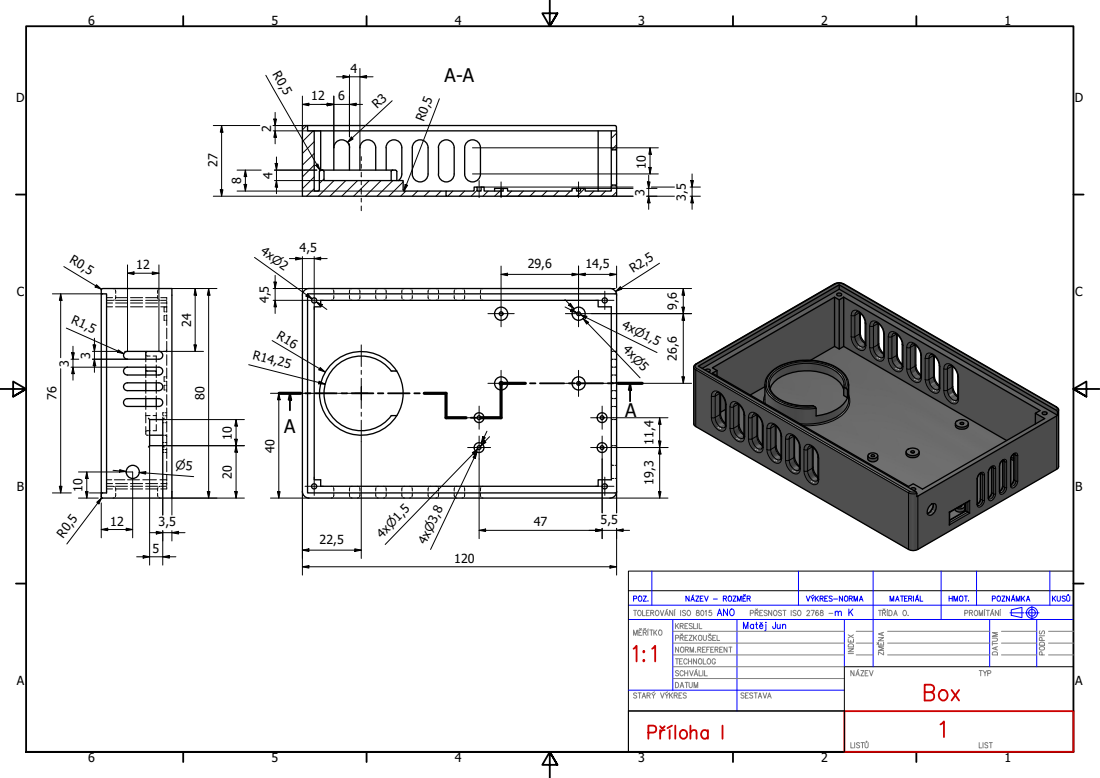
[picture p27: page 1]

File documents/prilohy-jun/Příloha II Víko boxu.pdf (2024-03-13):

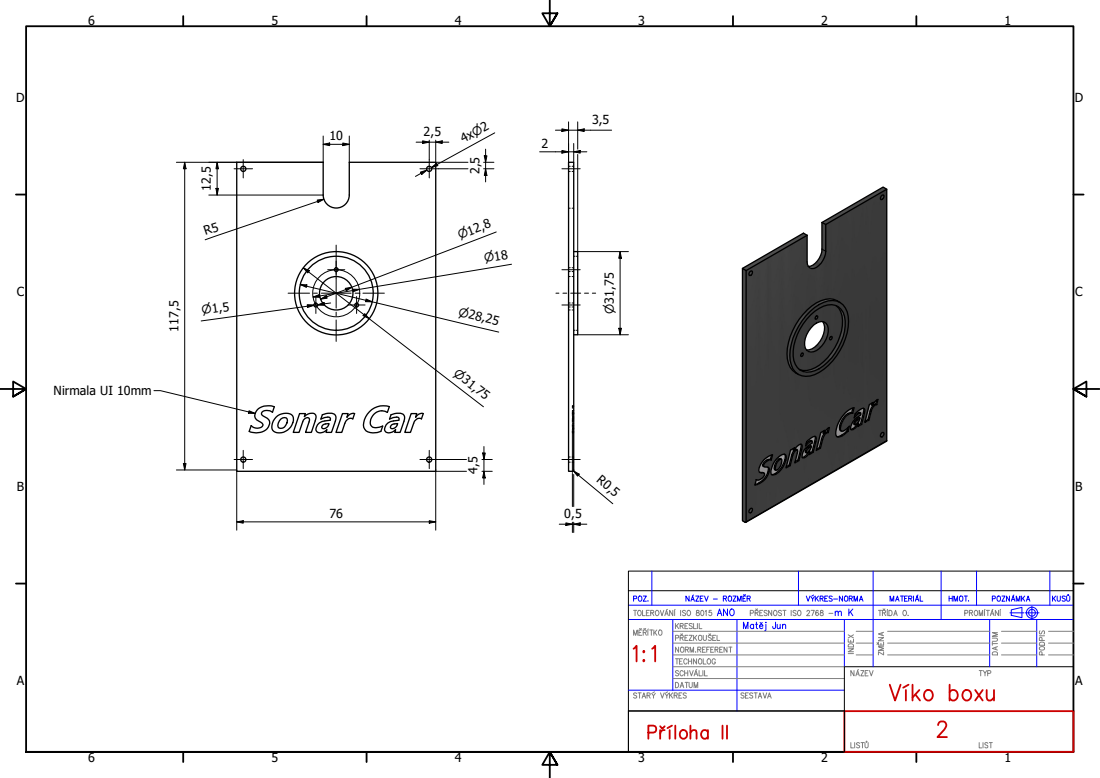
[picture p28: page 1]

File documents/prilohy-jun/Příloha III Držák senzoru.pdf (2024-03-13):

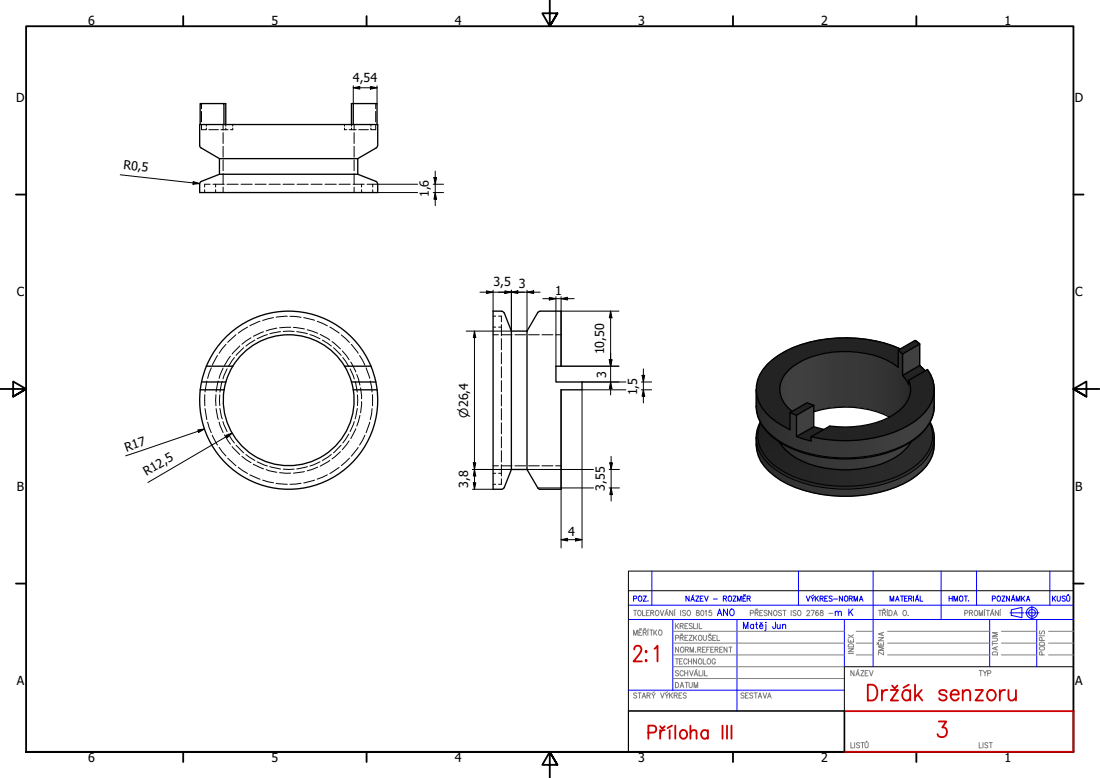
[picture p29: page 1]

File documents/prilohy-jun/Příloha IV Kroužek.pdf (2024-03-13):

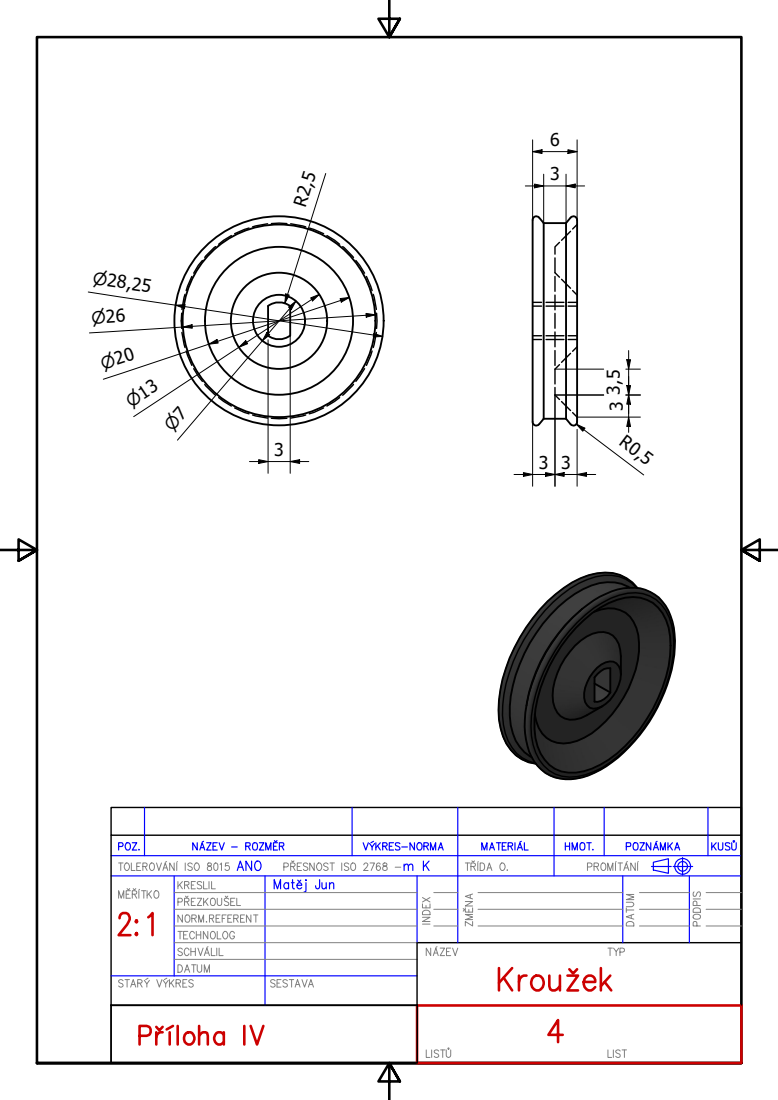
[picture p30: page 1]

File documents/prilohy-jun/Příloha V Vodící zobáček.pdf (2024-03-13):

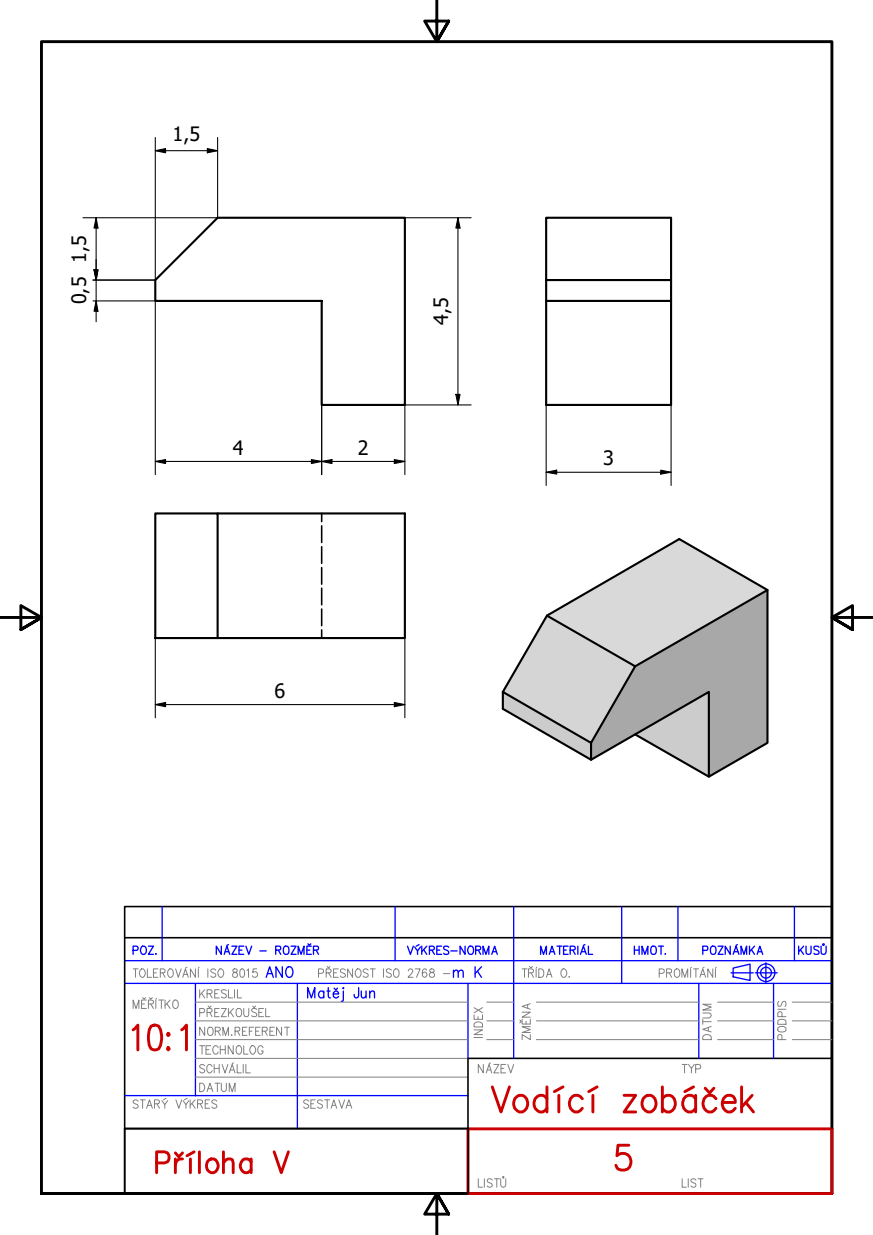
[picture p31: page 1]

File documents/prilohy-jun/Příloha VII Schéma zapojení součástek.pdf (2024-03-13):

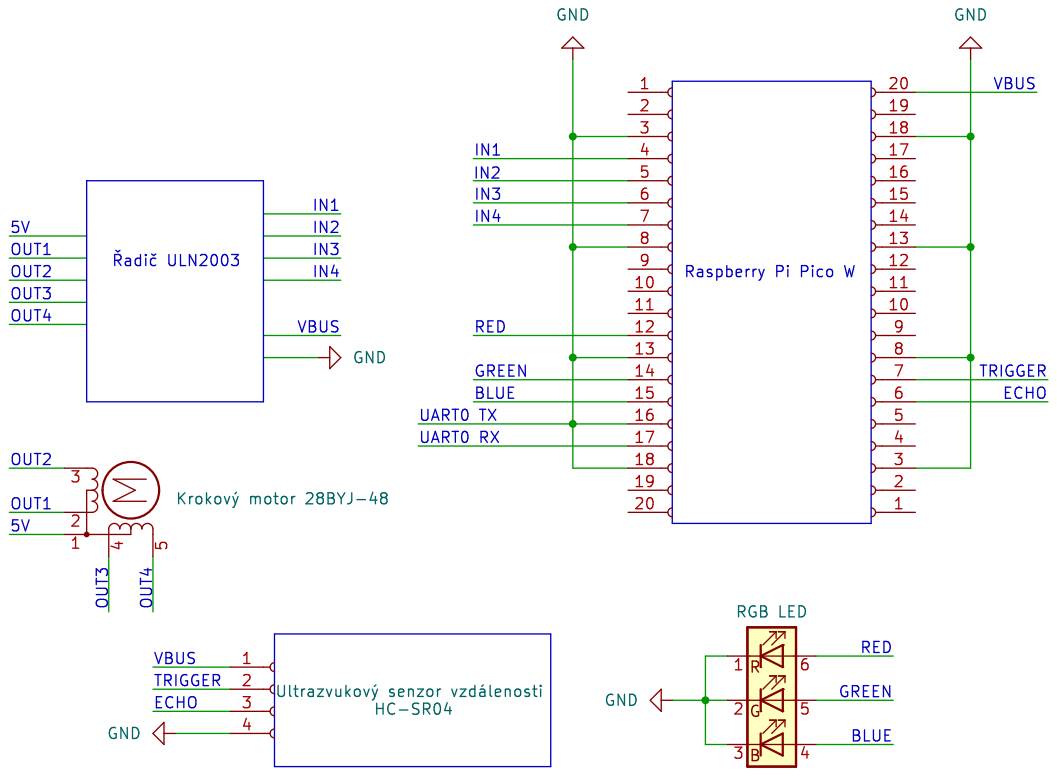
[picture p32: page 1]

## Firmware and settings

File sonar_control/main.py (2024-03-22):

# Main program for the sonar control system
# Draws 32 by 32 grid with walls and empty space
# grid points will be 10 cm apart
# Point value will represent probability of wall, 0 - no wall, 100 - wall

# Import necessary libraries
import periscope
import SignalLED as sl
from machine import Pin
import machine
from time import sleep
import mqtt
import where2go
from comms import Communication
import gc
gc.enable()

com1 = Communication(uart_id=0, baud_rate=9600)

# Define pins for the motor and sonar
motor_pins = [Pin(2, Pin.OUT), Pin(3, Pin.OUT), Pin(4, Pin.OUT), Pin(5, Pin.OUT)]
trigger_pin = Pin(21, Pin.OUT)
echo_pin = Pin(20, Pin.IN)

grid_size = 32		# Size of the grid (in points)
point_distance = 10	# Distance between points in cm

# Create a periscope object
scope = periscope.periscope(motor_pins, trigger_pin, echo_pin)

#map_plane = [[0 for i in range(grid_size)] for j in range(grid_size)]

def spawn_car(map_plane, x, y):
    if 0 < x < len(map_plane) - 1 and 0 < y < len(map_plane[0]) - 1:  # Ensure coordinates are within bounds and not blocking walls
        map_plane[x][y] = "S"
        return x, y
    else:
        raise ValueError("Invalid car position. Coordinates must be within the room bounds.")

angle_per_step = 21.97265625 # With the gearbox

def main():
	try:
		scope.setAngle(0)
		scope.setStepRatio(angle_per_step)
		print("Map is set to " + str(grid_size) + "x" + str(grid_size) + " grid with " + str(point_distance) + " cm distance between points (" + str(grid_size*point_distance) + "x" + str(grid_size*point_distance) + " cm) \nPlease wait for map to create...")
		mqtt.mqtt_send("Map is set to " + str(grid_size) + "x" + str(grid_size) + " grid with " + str(point_distance) + " cm distance between points (" + str(grid_size*point_distance) + "x" + str(grid_size*point_distance) + " cm). Please wait for map to create...")
		while True:
			map_plane = [[0 for i in range(grid_size)] for j in range(grid_size)]

			for i in range(0, 360, 5):
				print("Rotating...")
				scope.rotate(i)
				sleep(0.1)
				print("Measuring...")
				distance = scope.measure()
				print("Angle: ", str(i), " Distance: ", str(distance))
				x,y = scope.getXY(distance)
				print("XY1 ok")
				x, y = int(x/point_distance), int(y/point_distance)
				print("XY2 ok")
				if x < grid_size and y < grid_size:
					try:
						map_plane[int(grid_size/2 + x)][int(grid_size/2 + y)] += 1
					except:
						print("Out of range, may be a sensor failure")

			gc.collect()
			print("Scan finished. Printing map:")
			sl.red()
			spawn_car(map_plane, int(grid_size/2), int(grid_size/2))
			"""for i in range(grid_size):
				print(str(map_plane[i]))"""
			mqtt.mqtt_send(map_plane)

			pohyb = where2go.GenerateMove(map_plane)
			com1.send(pohyb)

			mqtt.mqtt_send("Program Done...")
			print("Program Done...")
			sleep(1)

	except OSError:
		machine.reset()
	except Exception as e:
		print("An unexpected error occurred:", e)
		mqtt.mqtt_send(f"An unexpected error occurred: {e}")
		sl.off()

if __name__ == "__main__":
	print("Sleeping 3s")
	gc.collect()
	sleep(3)
	main()

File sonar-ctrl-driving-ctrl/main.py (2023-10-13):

import machine
import utime
import math
from machine import Pin
from utime import sleep

pin = Pin("LED", Pin.OUT)

def LED():
    print("LED")
    pin.on()
    sleep(1)
    pin.off()
    sleep(1)

LED()

# Inicializace GPIO piny pro krokový motor
motor_pins = [machine.Pin(2, machine.Pin.OUT), machine.Pin(3, machine.Pin.OUT), machine.Pin(4, machine.Pin.OUT), machine.Pin(17, machine.Pin.OUT)]
step_sequence = [[1, 0, 0, 1], [1, 0, 0, 0], [1, 1, 0, 0], [0, 1, 0, 0], [0, 1, 1, 0], [0, 0, 1, 0], [0, 0, 1, 1], [0, 0, 0, 1]]

# Inicializace GPIO piny pro HC-SR04
room_map = {}  # Mapa místnosti, kde každá buňka je 10x10 cm
robot_position = (0, 0)  # Aktuální pozice vozítka v buňkách
robot_angle_degrees = 0  # Aktuální úhel vozítka (0 stupňů je směr nahoru)

# Funkce pro získání vzdálenosti ze senzoru HC-SR04
def get_distance():
    TRIG_PIN = machine.Pin(20, machine.Pin.OUT)
    ECHO_PIN = machine.Pin(21, machine.Pin.IN)

    TRIG_PIN.value(1)
    utime.sleep_us(10)
    TRIG_PIN.value(0)
    
    while ECHO_PIN.value() == 0:
        pulse_start = utime.ticks_us()
    
    while ECHO_PIN.value() == 1:
        pulse_end = utime.ticks_us()
    
    pulse_duration = utime.ticks_diff(pulse_end, pulse_start)
    distance = pulse_duration / 58  # Vzdálenost ve cm (rychlost zvuku ve vzduchu je přibližně 343 m/s)
    
    return distance

# Funkce pro otočení krokového motoru o 90 stupňů
def rotate_motor_90_degrees():
    for i in range(512):
        for halfstep in range(8):
            for pin, value in zip(motor_pins, step_sequence[halfstep]):
                pin.value(value)
            utime.sleep_us(1000)  # Zpoždění mezi kroky

# Funkce pro aktualizaci mapy na základě dat z ultrazvukového čidla
def update_map(distance, angle_degrees):
    global room_map, robot_position, robot_angle_degrees
    
    # Převod úhlů na radiány
    angle_rad = math.radians(robot_angle_degrees + angle_degrees)
    
    # Vypočet nové pozice na mapě
    new_x = robot_position[0] + int(distance * math.cos(angle_rad) / 10)  # 10 cm za jednotku
    new_y = robot_position[1] + int(distance * math.sin(angle_rad) / 10)  # 10 cm za jednotku
    
    # Aktualizace mapy
    room_map[new_x, new_y] = 1  # Značíme buňku jako překážku
    
    # Aktualizace pozice vozítka
    robot_position = (new_x, new_y)

try:
    # Ovládání krokového motoru pro otáčení o 360 stupňů s mapováním
    for i in range(4):  # 4 zastávky o 90 stupních
        for angle_degrees in range(0, 360, 5):  # Postupné otáčení
            rotate_motor_90_degrees()
            distance = get_distance()
            update_map(distance, angle_degrees)
        
        # Po každé zastávce otočte vozítko o 90 stupňů
        rotate_motor_90_degrees()
        robot_angle_degrees += 90
    
    # Výpis výsledné mapy
    for y in range(-10, 11):
        for x in range(-10, 11):
            if (x, y) == robot_position:
                print("R", end=' ')  # Aktuální pozice vozítka
            elif (x, y) in room_map:
                print("1", end=' ')  # Překážka
            else:
                print("0", end=' ')  # Volný prostor
        print()

finally:
    # Vypnutí motoru a uvolnění GPIO pinů
    for pin in motor_pins:
        pin.value(0)

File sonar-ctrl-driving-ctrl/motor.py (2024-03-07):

import machine
from utime import sleep_us, sleep

motor_pins = [machine.Pin(2, machine.Pin.OUT), machine.Pin(3, machine.Pin.OUT), machine.Pin(4, machine.Pin.OUT), machine.Pin(5, machine.Pin.OUT)]
step_sequence = [[1, 0, 0, 1], [1, 0, 0, 0], [1, 1, 0, 0], [0, 1, 0, 0], [0, 1, 1, 0], [0, 0, 1, 0], [0, 0, 1, 1], [0, 0, 0, 1]]


def reset_motor_pins():
    for pin in motor_pins:
        pin.value(0)

def rotate_motor_90_degrees():
    steps_per_90_degrees = 128  # Adjust this value according to your motor and setup
    for _ in range(steps_per_90_degrees):
        for halfstep in range(8):
            for pin, value in zip(motor_pins, step_sequence[halfstep]):
                pin.value(value)
            sleep_us(1000)
    reset_motor_pins()

try:
    # Continuous rotation
    while True:
        # Rotate the motor by 90 degrees
        rotate_motor_90_degrees()
        sleep(0.5)
except KeyboardInterrupt:
    # Nastavení všech motorových pinů na hodnotu 0
    reset_motor_pins()
    print("Motor pins reset")

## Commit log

2023-10-06 wheels
    x
    [printables-omniwheels.3mf]
2023-11-04 s
    s
    [rpi-holder.kicad_pcb, rpi-holder.kicad_sch]
2023-11-04 cs
    cs
    [rpi-holder.kicad_pcb, rpi-holder.kicad_sch]
2023-11-04 urcite umim s kikadem XD
    [rpi-holder.kicad_pcb, rpi-holder.kicad_sch]
2024-01-29 sonar model in progress
    [box.ipt]
2024-01-30 sonar box, support ring - test
    [box.0007.ipt, box.ipt, support-ring.0001.ipt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]
2024-02-06 t
    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
    [Sonar-Box.0031.iam, Sonar-Box.0033.iam, Sonar-Box.iam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]
2024-02-13 HIT THAT PRINT
    [box-top.0019.ipt, box-top.0021.ipt, box-top.ipt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]
2024-02-18 edit modelu
    [Sonar-Box.0036.iam, Sonar-Box.0038.iam, Sonar-Box.iam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]
2024-02-23 sonar mapa atd
2024-02-27 fixnutej sonar aby nelital, edit kodu na sonar
    [Sonar-Box.0038.iam, Sonar-Box.0040.iam, Sonar-Box.iam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]
2024-02-27 Mecanum Omni Wheels
2024-03-04 test
    zmena pinu, pridani reset_motor_pins, testovani
    [main.py]
2024-03-06 Add files via upload
    :D
    [karoserie.0015.ipt, karoserie.ipt, podvozek.0010.ipt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]
2024-03-13 VYKRESYD?SAYDfsadfsaagfdsg
    gdfhgdsfhgf
    [Příloha II Víko boxu.0002.dwg, Příloha II Víko boxu.dwg, Příloha III Držák senzoru.dwg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]
2024-03-16 wireless mqtt controlesr
